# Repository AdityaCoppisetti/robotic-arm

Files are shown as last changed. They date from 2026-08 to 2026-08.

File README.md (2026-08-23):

# 6-Axis Robotic Arm

This project is a custom-built 6-axis robotic arm that I designed and built from the ground up. 
The arm has six degrees of freedom thus the 6DOF , I designed the mechanical parts myself and used a combination of 3D printing, custom gears ,and  almost each joint is a planetary mechanism since i really wanted to learn that and i learnt that in onshape .  The gripper usse MG996R V17 servo

The control side of the project is a custom pcb which is handled by a custom arduino uno nano that i made . the main pcb usees a4988 stepper motor drivers to drive each and every motor and the servo motor for the gripper i have connected directly . The plan is to use forward and inverse kinematics to move to a specific point instead of manually controlling every joint.

One of the things I want to experiment with later is turning the arm into a 3D printer by replacing the gripper with a printing head. This would make the robot more than just a robotic arm and i could then print alot of stuff from a arm that itself was 3d printed bahahahhahahaa

 There will probably be a lot of redesigns, and ill keep updating the journal.md of this repo for that 



i designed this robotic arm in onshape, 

joint 1 - 5 uses planetary gear mechanism where the sun gear is attached to the nema 17 motor



and then ive made the claw/ gripper 
which uses a servo motor attached to a spur gear which move yet 2 another spur gears



# how to assemble 

print the given step files , modify them if you want to 

and then look at the assembled version and piece everything together. i will be documenting my proccess aswell when i print the parts. 

# how to assemble electronic part of project

when you get the main pcb and then the microcontroller pcb
you take the stencil and then use that stencil to apply solder paste. 
and then you remove the stencil and place each component by looking at the nicely labelled pcb 



and then by using a hot air gun or a hotplate , reflow the solder 

# hot to assemble the main board pcb 

you take the pcb and using a soldering iron just solder the required amount of female or male pinheaders ( 2.57mm exactly) 

Screenshot From 2026-08-21 19-59-14

here is a mockup i nade using onshape of how the main pcb should look like after you assemlbe it

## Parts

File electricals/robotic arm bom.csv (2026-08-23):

No. | Component / Item | Price (inr) | Source / Purchase Link | Price (USD)
1 | Nano PCB | 900 | Robu.in | $9.40
2 | Main PCB | 1850 | Robu.in | $19.33
3 | Solder Wire | 229 | https://www.amazon.in/dp/B0GY9Q2VXC/ref=twister_B0GY9X7NQT?_encoding=UTF8 | $2.39
4 | PLA Filament | 699 | https://www.amazon.in/PLA-3D-Flexibility-Eco-Friendly-Compatible/dp/B071D82LDV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 | $7.30
5 | NEMA 17 Stepper Motor - 17HS4401S | 3204 | https://robocraze.com/products/17hs4401s-nema-17-stepper-motor?_pos=2&_psq=nema+17&_psid=cc221da5e&_ss=e | $33.48
6 | Zip Ties | 99 | https://www.amazon.in/gp/product/B08GKPWLB9/ref=ewc_pr_img_4?smid=AJ6SIZC8YQDZX&psc=1 | $1.03
7 | DC Power Jack Adapter - 2.1 × 5.5mm | 19 | https://robu.in/product/male-female-2-15-5mm-dc-power-jack-adapter-connector-plug-cctv-camera/ | $0.20
8 | 12V 1.5A Power Supply | 219 | https://www.amazon.in/gp/product/B0H1CTJV1Y/ref=ewc_pr_img_1?smid=A2DCS35WT32C19&psc=1 | $2.29
9 | A4988 Stepper Motor Driver + Heatsink | 432 | https://robocraze.com/products/original-a4988-stepper-motor-driver-module-with-heat-sink-for-3d-printer-red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 | $4.51
10 | 5-inch HDMI Touchscreen Display - 800×480 | 2359 | https://robu.in/product/5-inch-touch-screen-hdmi-interface-display-module-tft-lcd-800x480-raspberry-pi-2-model-b-touch-pen/ | $24.65
11 | Mechanical Switches | 399 | https://www.amazon.in/gp/product/B0FPR2ML31/ref=ox_sc_act_image_2?smid=A16FKXBMFHBYH0&psc=1 | $4.17
12 | Raspberry Pi Zero | 2000 | OLX.in bought it second hand , need reimbursement | $20.90
13 | 608 ZZ Bearing | 265 | https://www.amazon.in/608-Pieces-Double-Shields-Bearing/dp/B0H5T479XF/ref=sr_1_10?sr=8-10 | $2.77
14 | 1µF 0603 SMD ceramic capacitor | 55 | https://robu.in/product/mc0603b105k160ct-multicomp-pro-cap-smd-mlcc-1%c2%b5f-16-v-0603-pack-of-5/ | $0.57
15 | 100nF 0603 SMD ceramic capacitor | 11.6 | https://robu.in/product/cc0603jrx7r7bb104-yageo-16v-100nf-x7r-%c2%b15-0603-multilayer-ceramic-capacitors-mlcc-smd-smt-rohs/ | $0.12
16 | 4.7µF 16V SMD capacitor | 38 | https://robu.in/product/0805yc475kat2a-kyocera-avx-smd-multilayer-ceramic-capacitor-4-7-%c2%b5f-16-v-0805-2012-metric-%c2%b1-10-x7r/ | $0.40
17 | Yellow 0805 SMD LED | 7.55 | https://robu.in/product/0805-surface-mount-led-yellow/ | $0.08
18 | Green 0805 SMD LED | 14.44 | https://robu.in/product/0805-surface-mount-led-red-50-pcs/ | $0.15
19 | Red 0805 SMD LED | 7.2 | https://robu.in/product/0805-surface-mount-led-red-50-pcs/ | $0.08
20 | MicroSMP Schottky diode | 40 | https://robu.in/product/mss1p3l-m3-89a-vishay-intertech-30v-1a-440mv1a-microsmp-schottky-diodes-rohs/ | $0.42
21 | 0603 SMD fuse | 6.25 | https://robu.in/product/1uf-1000nf-50v-capacitor-0603-smd-package-pack-of-20/ | $0.07
22 | Mini USB-B female horizontal connector | 145 | https://robu.in/product/u-m-m5ss-w-2-hroparts-usb-2-0-1-5p-female-mini-b-smd-usb-connectors-rohs/ | $1.52
23 | 2.54mm pin header, 1×40 | 69 | https://robu.in/product/ds1021-1x40sf11-b-connfly-1x40-pin-2-54mm-pin-header-v-t-type/ | $0.72
24 | 1KΩ 0603 SMD resistor | 9 | https://robu.in/product/1k-ohm-1-4w-0603-surface-mount-chip-resistor-pack-of-100/ | $0.09
25 | SMD tactile switch, EVQPUK-style | 45 | https://robu.in/product/pts526sp20smtr2-lfs-ck-smd-tactile-switches-rohs/ | $0.47
26 | ATmega328P-M, QFN-32 5×5mm | 955 | https://robu.in/product/atmega328p-mur-microchip-8-bit-mcu-low-power-high-performance-avr-atmega-family-atmega328-series-microcontrollers-avr/ | $9.98
27 | LM1117MP-5.0, SOT-223 | 140 | https://robu.in/product/lm1117s-5-0-5v-1a-fixed-output-ldo-linear-voltage-regulator-3-pin-sot-223/ | $1.46
28 | FT232RL, SSOP-28 | 465 | https://robu.in/product/ft232rl-usb-to-ttl-5v-3-3v-download-cable-to-serial-adapter-module-for-arduino/ | $4.86
29 | 16MHz 3-pin SMD ceramic resonator | 50 | https://robu.in/product/1-month-warranty-802/ | $0.52
30 | raspberry Pi Zero cables and adaptor | 142 | https://robu.in/product/raspberry-pi-zero-3in1-micro-usb-cablepin-headerhdmi-adapter/ | $1.48
31 | velcro for claw/ gripper | 185 | https://amzn.in/d/0eumMNpg | $1.93
 |  |  | Total = $157.34 USD.

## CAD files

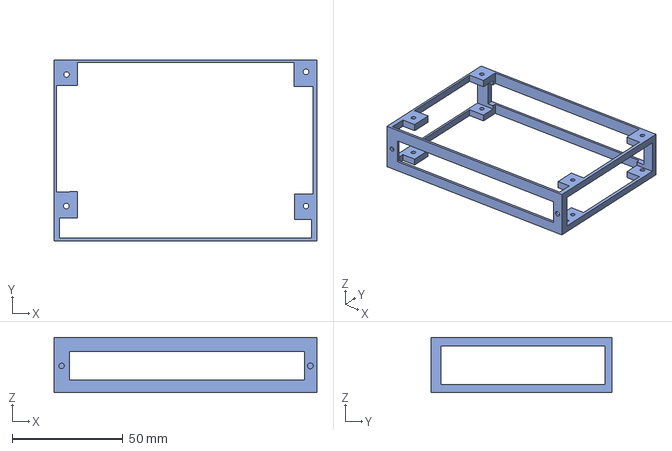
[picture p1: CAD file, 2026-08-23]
Robotic arm cad/main pcb case - Part 1.step
119.0 x 82.0 x 25.0 mm

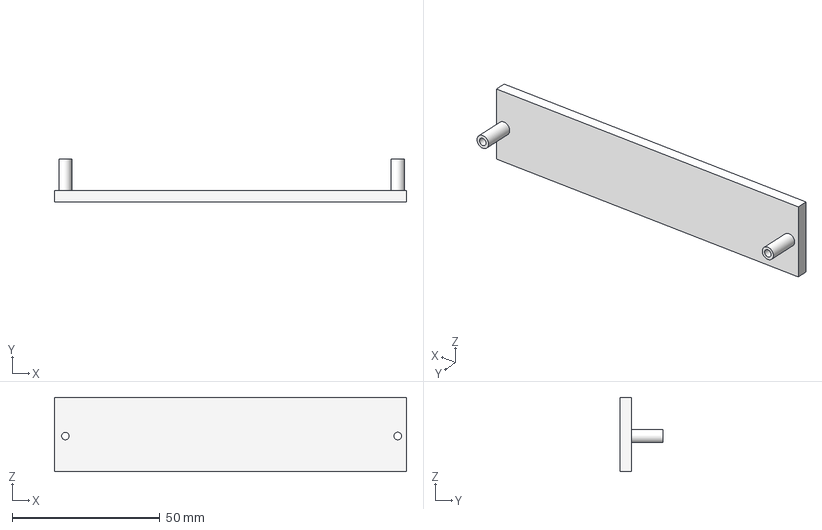
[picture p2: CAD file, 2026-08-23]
Robotic arm cad/main pcb case - Part 2.step
119.2 x 14.6 x 25.2 mm

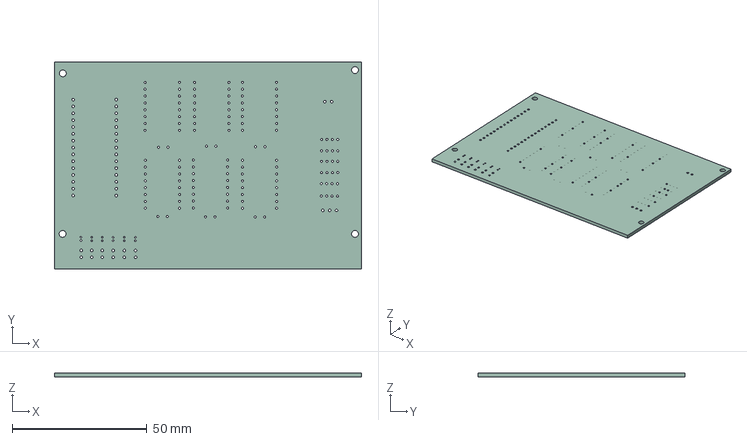
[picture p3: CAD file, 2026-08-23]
Robotic arm cad/main pcb.step
113.8 x 76.9 x 1.51 mm

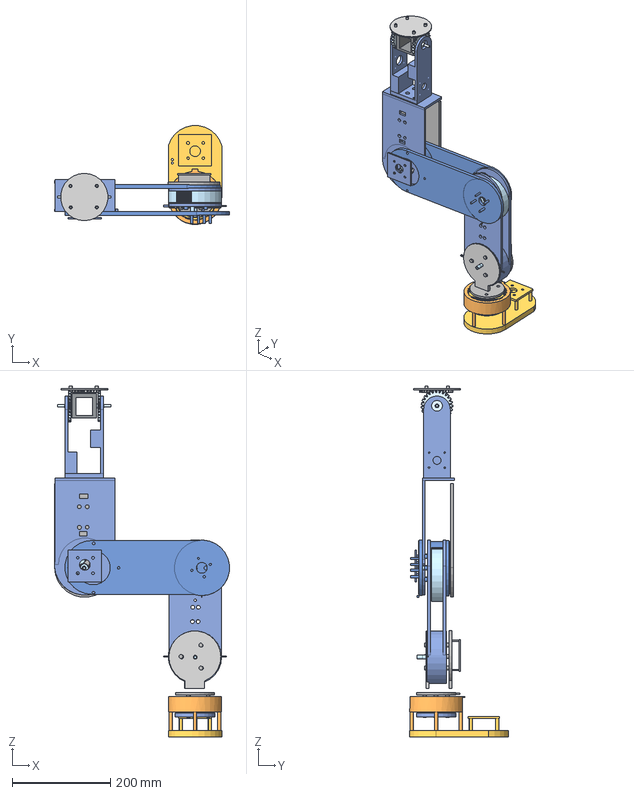
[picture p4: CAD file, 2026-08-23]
Robotic arm cad/assembled arm.step
357.1 x 201.3 x 716.0 mm
Spur gear (25 teeth) x 3

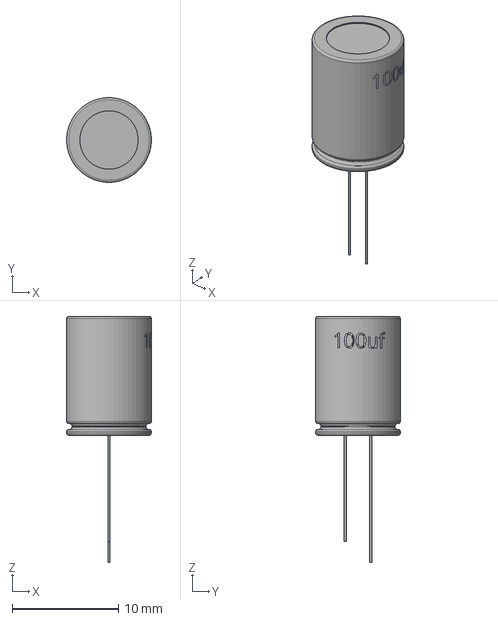
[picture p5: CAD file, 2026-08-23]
Robotic arm cad/100uf capacitor.step
8.00 x 8.00 x 23.2 mm

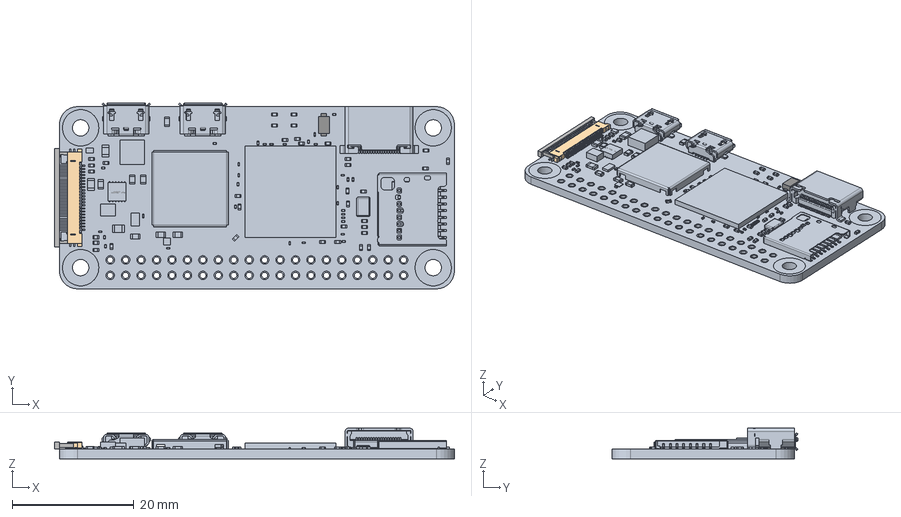
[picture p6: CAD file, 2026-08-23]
Robotic arm cad/Raspberry Pi Zero 2 W with Textures.step
65.8 x 30.6 x 5.05 mm

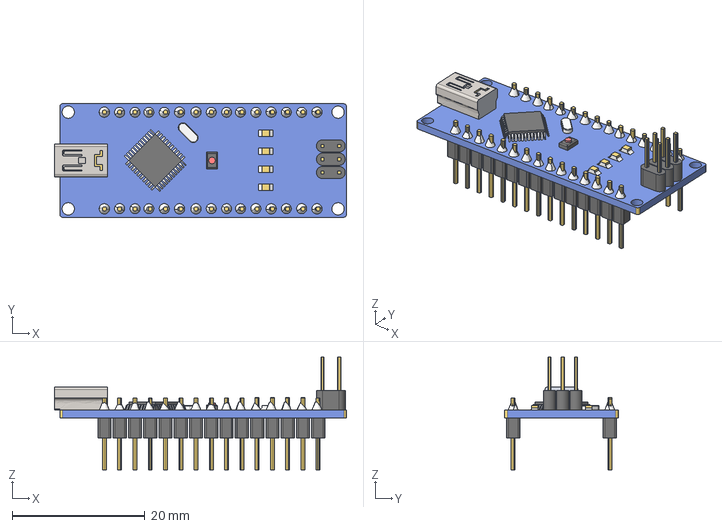
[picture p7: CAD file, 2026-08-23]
Robotic arm cad/Arduino Nano cadddddd.step
44.0 x 17.1 x 17.0 mm

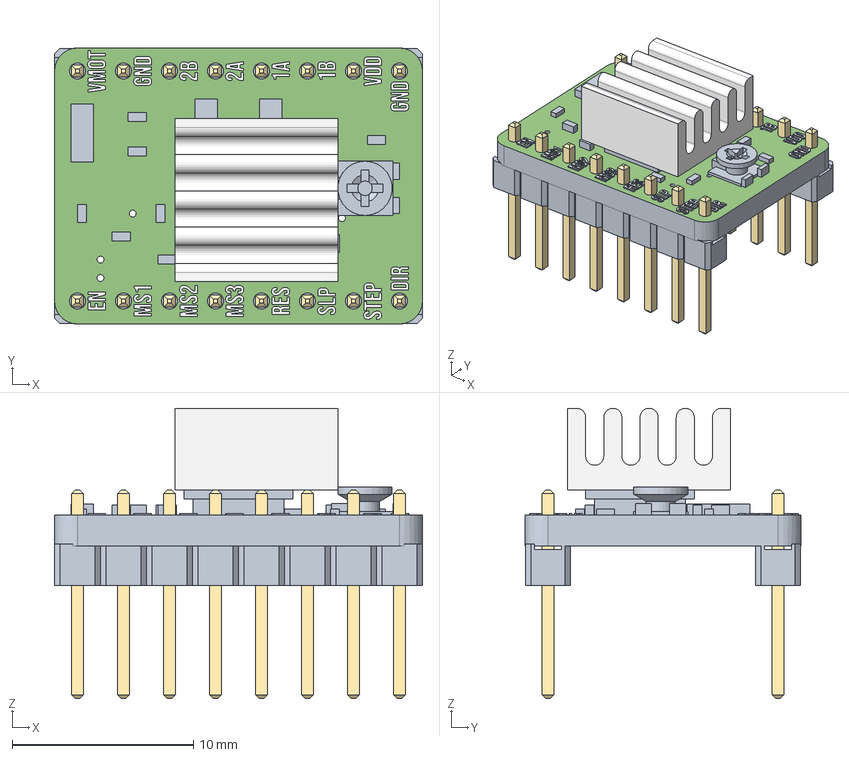
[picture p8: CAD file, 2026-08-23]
Robotic arm cad/a4988.step
20.3 x 15.2 x 16.0 mm

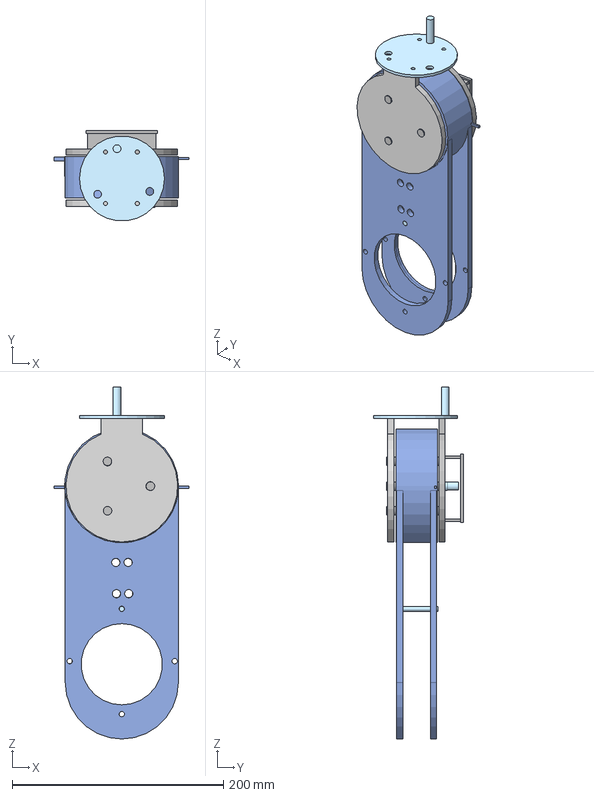
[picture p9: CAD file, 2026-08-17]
Robotic arm cad/joint 2 and link 2.step
127.9 x 85.7 x 333.5 mm

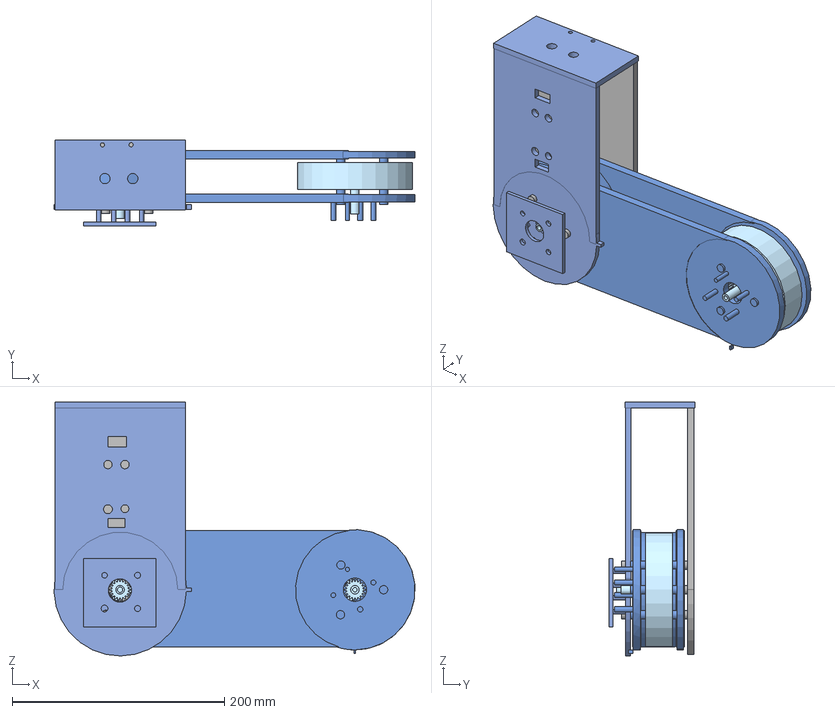
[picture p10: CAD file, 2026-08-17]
Robotic arm cad/joint 3 and joint 4 , link 3 and link 4 .step
339.9 x 80.5 x 239.0 mm

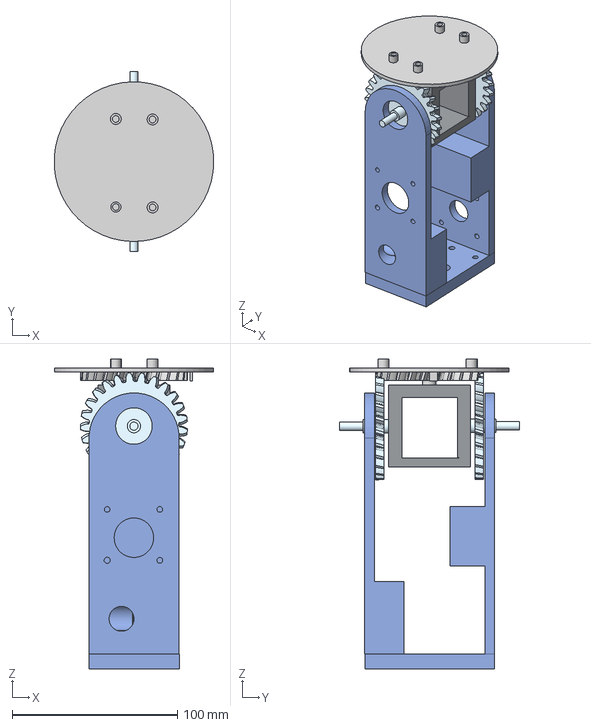
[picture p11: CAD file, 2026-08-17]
Robotic arm cad/2 DOF WRIST.step
96.4 x 109.0 x 187.4 mm

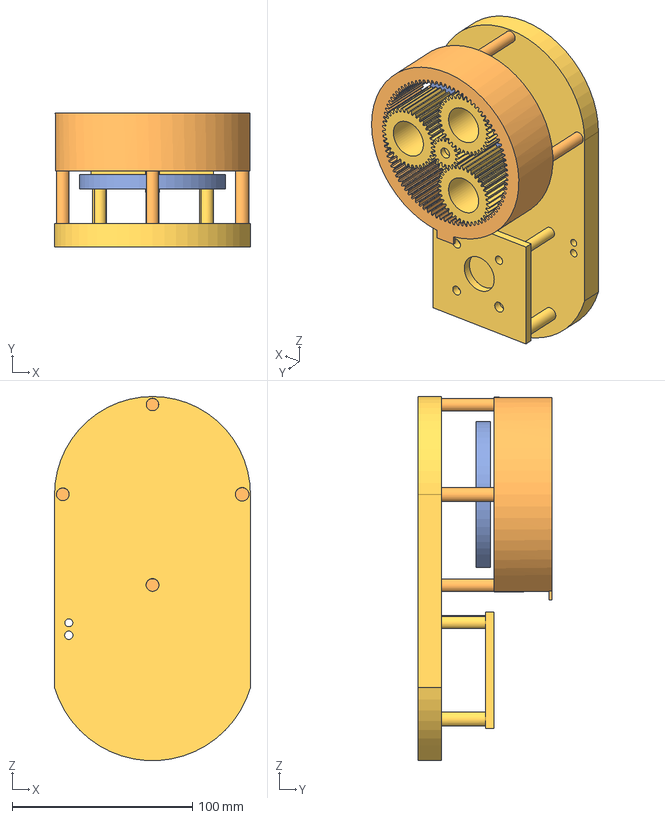
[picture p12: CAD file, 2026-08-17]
Robotic arm cad/base actuator.step
108.8 x 74.2 x 202.0 mm

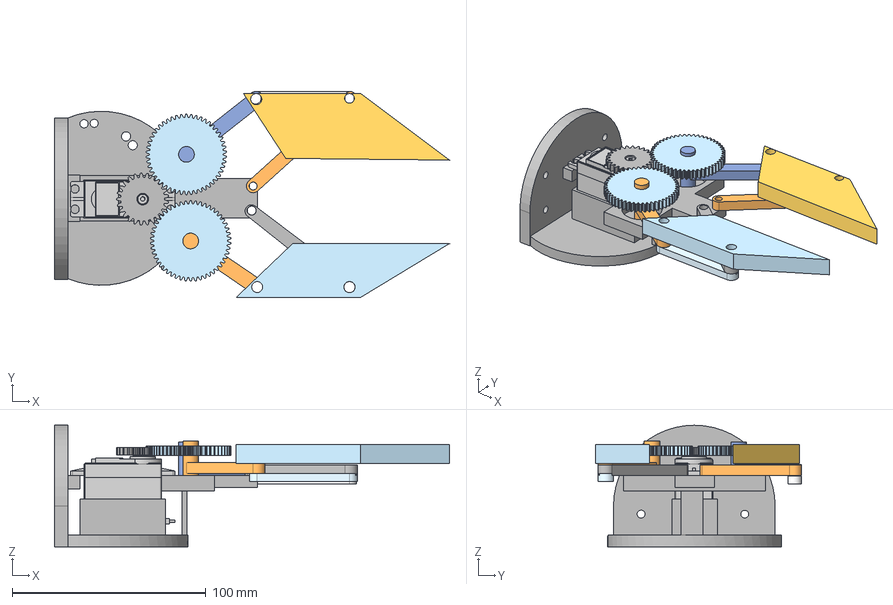
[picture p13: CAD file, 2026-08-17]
Robotic arm cad/claw-gripper.step
203.9 x 106.3 x 62.7 mm

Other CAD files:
Robotic arm cad/MG996R Servo Motor.x_t

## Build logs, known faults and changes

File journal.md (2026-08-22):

this is where ill be journaling my work.

Date- june-12/2026

time: 5:41 AM
today is 12th june but this is the work that i did on june 11th. due to a hectic and hot day i forgot to journal my work.

# THE ROBOTIC ARM BASE DESIGN

so i was searching for way to make this , thinking of a ton of designs and i thought this would be really easy. i was wrong.
i took me 45 mins until i landed on this- https://www.printables.com/model/930858-3d-printed-robotic-arm-actuator/files
this is whats called a planetary gear mechanism. very popularly used amoung projects like this.
Planetary gear mechanisms provide superior high torque density, allowing them to transmit large loads in a compact, lightweight design by distributing force across multiple planet gears



and i thought this would be incredibly easy to make but i was incredibly wrong.
until i picked up this project i didnt even know what a planetary gear shift system is. i have never worked on stuff like this and this is my first time using cad aswell.

i found this of great help! -https://www.thecatalystis.com/gears/
this is a website that helps you simulate the planetary gear system.
i was thinking of 3d printing the gears aswell but i found cheap planet gears on amazon- 
https://www.amazon.in/gp/product/B0G2J7PGLC/ref=ox_sc_act_image_1?smid=A3MLO3EZOE585&psc=1
the reason i went with this is of the material they are made of(nylon) and the fact they come pre prepared with bearings.

Screenshot From 2026-06-12 05-52-59

now now its okay if you want to save money and print the planet gears yourself, you can do that just double click on the mechanism and 
press center bore and then put the diameter bearing youre using

and so i opened the plantery mechanism similation on the website and typed in - 36 teeth in the planet ring.
and it gave me the other info that i needed.



and so i opened onshape and started a new document. 

you have to press the add custom feature button on the toolbar



and then you have to press this 



and then just search planetary gear.

you then have to go back to the planetary gear simulation and fill in the information accordingly.



MAKE SURE YOU PUT THAT YOU HAVE 3 PLANET RINGS.

( a few hours ago i had no clue what onshape even was and now im teaching in my github repo like wow what a nerd)

IF YOU EVER WANT TO LEARN MORE ABOUT GEARS AND THEIR MECHANISMS HERE IS THE BEST SITE IN MY OPINION-
https://www.3dmechanism.com/

now that the mechanism is done we have to work on whats called the **CARRIER**

now there are alerady a ton of good pre made designs in the onshape public library which i couldve used but once again this was my first time working with gears , cad and the whole circus.
so i desiced it was a good learning moment and i fucked around to find out.
here is the design i saw and i wanted to make this but i took me a WHILE to find out how this works.



this is the carrier design i had in mind. now this carrier is pretty well made but i wanted to know how it worked.
i couldnt use this carrier design exactly because its for 4 planets while we are only using 3. i think 3 is plenty
i couldve used just a simple triange as a carrier because of three planets but i lowk didnt know where or how to make a triangle like this-



but i did not understand it and that helped me in its own way.

i reverse engineered this- 



and made my own-
( i know it aint that good but its workable)



this is the base of the carrier because of the centre hole thats there so i can connect the sun gear ( the middle one) to the stepper motor.

and then this is the top one 


and then put together it looks something like this- 
all of this, including figuring out how to do cad and how onshape works and what planetary gear mechanism took me about 4 hours to figure out.

https://github.com/user-attachments/assets/15bbe72e-d050-4046-b9d4-a2d1aa677c6d

time logged- aprox 4.2hours

date- july 8th, 2026

yes i havent worked on this project in a while.
but i have made tons of progress

i made multiple joints. 
at first i was really really confused about what and how im gonna make the other joints. 
it may be because i havent done this kind of work in a while. it feels refreshing and really good to get my mind working again. 

ive made until this and only one portion remains. 

Screenshot From 2026-07-08 18-09-43

i know i know it looks weird but this is my first time making one and that includes first time using cad.

Screenshot From 2026-07-08 18-08-47

## okay so now onto the joint 2.



my idea was that if the planetary gears stay in place , the sun gear obviously stays in the middle, 
by that logic then the outer ring would rotate.

this is what i meant. 
i used the https://www.thecatalystis.com/gears/ website to demonstrate my idea.

https://github.com/user-attachments/assets/46c02f40-51b7-4518-86ec-1d51c42bed83

this is basically what i meant. 
notice how the outer ring is spinning and the planetary gears are spinning but not moving their positions.
also notice that the sun gear is moving in the opposite direction for it to move clockwise.

sun gear=anti clockwise
outer ring= clockwise.

keep this in mind cause its gonna be cruical to not forget.

in the "carrier" that puts the planetary gears in their position , i wanted to put small holes to put heat inserts into but onshape is glitching and not letting me do that so i might drill a little hole and put the heat insert that way



i put this motor mount but i lowk want to make it better which i will later on. instead of wasting filament to add structure i might just put like really long screws.



ALSO a really big mistake i made was that i was doing this to increase the length of my gears and allat. 

https://github.com/user-attachments/assets/ec140412-38f2-4429-8a6d-367094285359

which was basically just me copying the part and then stacking it on top of it and then combining it into one singular part using the boolean feature. 
it was extremely time taking oh god so i looked around and let me tell you that i felt like a dumbfounded idiot when i found that i can just do this

https://github.com/user-attachments/assets/3397579b-ed96-481c-a308-d51986f8bd29

you can just change the extrude depth here.



cause this at the same time makes the gear length also bigger.

this is my logic.



there is a tinyyyy tinyyyy gap there and i will be putting whats called a lazy susan bearing



this allows me to mount the pieces and let them carry that weight and not just hang from the carrier , but also the main support structure.

and then this is what the forearm looks like. it has holes to mount the outer ring to.



okay so earlier what we were doing was the outer ring was moving. 
but for this joint. the outer ring will be mounted to the forearm and the carriers will move. 
this is good for the weight distrubution.

this also gives me the excuse to use belt mechanism. i will be updating that dw. 

## now onto the joint 3.

i left a gap so that we could mont the outer ring carefully.



i put some holes in the ring because we need to mount it so we will put a thread insert.





these are to keep the gears in their disired spot



and then those "carrier are connected to another forearms and then connected to its own "outer ring" . 

all together it looks like this 



and then i made this. the forearm is short and then there is a flat sqare put on it. why? ill explain later. 

Screenshot From 2026-07-09 01-02-05

Screenshot From 2026-07-09 01-02-09

Screenshot From 2026-07-09 01-02-21

see the thing is for the wrist movement and attachment i want to make something like this- 

Screenshot From 2026-07-08 18-21-21

source- https://www.instructables.com/Yet-Another-3D-Printed-Robot-Arm/ 

you just have to scroll down a ton. dw its there. 

https://github.com/user-attachments/assets/bfe6638c-dc26-4a09-b7fa-06951944e07d

this is basically how it'll work. seems complicated but i know it isnt, pretty simple actually. 

https://github.com/user-attachments/assets/02b2b4d9-ed3f-49f6-b729-89860f96fb4b

I SAW THIS REEL WHERE THE MOTOR COVER , the filament part on the side was resin printed so it was CLEARRRRRRRRRRR WHICH WAS SO FUN!!!

I REALLY REALLY WANT TO DO THAT IF MY BUDGET HAS ANY ROOM. 

https://github.com/user-attachments/assets/cf3f4451-7ed7-4512-8826-a6093ded6a33

## august 2nd time - 10.54

# i just got done rebuilding the base of the robotic arms. 
there were several flaws -
1) the motor mount wasnt good and would leave the motor sitting by itself or like lifting the entire load.
2) i intend to use a belt driven planetary gear mechanism and that design wount let me do that so i had to redesigns everything
3) the base was too weak to carry the weight
4) there wasnt any space for limit switches
5) i increased the planetary gear depth and so needed to update the carrier since it was too short and wouldnt work

like look at how thin and bad it was previously- 



i think it had so many flaws because it was the first thing i had designed in cad after a LONGGGGG TIME 
so after a ton of practice building this project and many other i got faimliar with the software and cad itself and got slightly better at it.

here is what the new design looks like- 

Screenshot From 2026-08-02 10-53-35

here is a video showing the design properly -

https://github.com/user-attachments/assets/b235d558-9b16-4ba0-b130-88022c7480a6

the base i made with the intent to mount the motor to 



this will hold the motor aswell as give support to the base actuator. 

i put holes beneath to put heat inserts and then use screws and washers to secure it properly



mounted it would look smth like this- 



## sun gear

i changed the sun gear kinda , i added this middle support so i can put the gear and belt mechanism properly 



this basically- 



i went ahead and made a hole in the sun gear support cylinder so i can mount the belt gear mechanism easily.



once again these are the gear teeth and allat 



and then the carrier , i just have a cylinder running between each of the gears



and then at the very end of those gears i have added holes for heat inserts 



once again ill be using washers and screws to mount them securely. 
atp i should just use mansory glue lmao

and then for the limit switches i made this pretty simple mechanism 



althought i do feel like i should make it a bit bigger. 

all put together it looks like this- 

## 

## August 2nd 6.27 
i made some changes in the **joint 2**

i made a proper space for the motor and i put a lil tab for the limit switches



not much a difference 

OH AND i also changed the base plate of this part so i t mounts properly and accurately. 

## August 3rd 2.13 pm

i worked on all the joint's motor mounts and in the end i made this i have very minor changes to make and now i have to make the last 2 axis mechanisms. 



better view- 

https://github.com/user-attachments/assets/d6cfd987-f96c-4dd9-8066-cd05eacd0aab

## AUGUST 6TH TIME- 4.08PM

i actually made the 2 dof wrist yesterday and i thought that would be it.

heres how it looked , i deleted the file due to so many inaccuracies



there are so many faults i cant even 

https://github.com/user-attachments/assets/077f853c-312a-4f89-8bd1-733a6afe177f

as it turns out my calculations where wrong and bisdes that i had done alot of things freehand, 
and so i needed to redesign the entire thing again but with precise calculations.
i have to say i had alot of fun making this.

i followed some youtube video ( not tutorials just demonstrations) and made the design in my mind first and then carried it out in onshape.

i ended up with this oh and i used helical gears



i know it looks like i can make it more compact but i did measure everthing and the nem17 motors are 40mm ( 4cm ) and they wouldnt fit at all.



there is this cylindrical shape so i can put it on gearing and itll be able to rotate freely



and then this is so that i can mount Aluminum Timing Pulley. its 5mm.



and i guess i can call this square a carrier?



it has space for the gearing from the other side to go and the gears would stay in place.



and then this is the top surface where ill later put the gripper claw.



i also need to put a camera mounting thingy so that i can later on put a camera on it. honestly just my phone beause i dont think itll be able to handle the weight of my camera.

# now onto the whole holder which will house the nem17 motor 

this is the left side,


i plan on mounting the stepper motors on top of each other 

the motor width regardless of the shaft is 40mm (4cm) and so i put a little back piece there so the motors have no place to slide

and ill just put a piece of cardboard there or smth i dont know plus it gives a lil space for the wires.

also now do i think about it i need to put a lil limit switch bar on the surface mount

i added this little piece so that i can use it to press limit switches i mounted it on the surface plated because the surface plate is the one thats moving in two axis



also these are the measurements for the nem17 motors i found from the robu.in website 



and then here is the schematic design 



AAAAAAAAAAAAA I STILL NEED TO DESIGN THE ELECTRICALS AFTER IM DONE W THE CAD AAAAAAAAAA 

oh yeah back to the holder for the motor and allat

i included this lill space so i can put the wires thru this which looks good ig idk 
this would make the wiring easier fsfsfsfs



i then made this bottom mount so , im gonna put in heat inserts and then screw everything into place, and then i added to holes so that i can mount it using screws and washers onot the robotic arm itself

all put togehter this looks something like this - 



https://github.com/user-attachments/assets/72c732a2-6be2-4c8c-96ef-66e903738f73

also i realised allmost everyone else my calculations for the motor are wrong so im going to fix that, only minor fixes nothing to worry about alot

## AUGUST 7TH 

I worked on making the shoulder of the robotic arm proper, the closer i look at my designs the more i realise how much i fucked up.

i made it a bit better but i know in the future ill look back and sigh with all the inconsistancies. 

this is the improved version- 



i improved the carrier , i want to add bearing between the sun and planet gears and so i made a centre bore.



oh and the bearing i want to use are the 608zz bearing and its dimentions are- 
i used the extrude feature to make the hole in the centre but you can just enter the dimension here - 



i also change the base mounting plate it was really shit 

 

i made 4 tiny hole to put the threaded insert inside and then those 3 holes along with that weird cylinder are to mount it on the base planetary mechanism itself.
i was at first thinking of adding screws but just cylniders and some glue will help, you'll understand what i mean when i build it irl. 

and then i fixed the motor mount



believe it or not the hand drawn motor mount i made previously was not that far off in terms of dimension so i made it PROPER proper ykwim. 

all together it looks something like this - 

For the 608ZZ bearing:

Measurement	Millimeters	Centimeters
Inner hole diameter	8 mm	0.8 cm
Outer diameter	22 mm	2.2 cm
Thickness (width)	7 mm	0.7 cm

So in centimeters:

Inner hole: 0.8 cm
Outer diameter: 2.2 cm
Thickness: 0.7 cm

oh and i dont know if i mentioned this before- 



these holes are so i can put zip ties and cable put my wires neatly. 

here is how it looks all together 

https://github.com/user-attachments/assets/92ba4edb-455b-4546-ade4-a52e37fcf780

oh and i fixed the measurements in the base part of the arm- 



i fixed the motor mount and then i fixed the sun gear so that i can put a belt mechanism on it. 



and here is a lil 360 of the base- 

https://github.com/user-attachments/assets/05f1c04c-e099-472e-9303-c13885892532

okay so i made these lil holes so that i can put heat insert (this is the wrist mechanism) 



this is so that i can mount anything i want on it with ease. 

oh and i went ahead and fixed this- 



i think the arm is coming into great shape- 



whats remaining is to make the claw/ gripper

oh and i updated this aswell- 



## AUGUST 8TH 8.12AM 
GOOOOOOOOOOOOOOOOOOOOOOOOOD MORNINGGGGGGGGGGGGGGGG 

yesterday i made the claw/gripper mechanism and i had alot of fun making it!
i had this design in my mind ever since i started



here is a tutorial kinda? its just saying how it works 
https://www.instructables.com/My-Big-Robot-Claw/

and basically how it works is- 

https://github.com/user-attachments/assets/29d53f73-7ce6-4bcc-ba2c-e7f5372ba941

 and so i started making the design in onshape and at first i made this disgusting design and thought it would be okay 

 Screenshot From 2026-08-07 17-57-44

yes i know it looks so bad. i lowkey thought i would leave it be but then i got this urge to make it better and i thought why not give it another try and i made this which is much better in my opinion



now this is much much better than the earlier design.



im using 3 spur gears , 2 of them connected to the claw mechanism itself and then one is connected to the servo motor.

in this design im using the TowerPro MG996R Digital High Torque Servo Motor.

this is better than the shitty low quality servo motor 

and i wanted to design my cad design as precise so i pulled out this specification of the motor

AWN9abVES4HJeKg18x0a8sXqbF1AeTm1wUe4BqLj

but then i did not want to redesign the entire motor in onshape so i looked in public documents if someone had already deisgned it for me and sure enough someone had deisgned it!



i did measure it to see if it was accurate and it is 

ill add the servo motor copy file into the repo!

all of this is making me wonder if i should redesign the forearms now cause they look really bad 

and so i followed that design on istructables.com and i made my design

here is how it looks like from beneath.

and then i made the the mount/ motor mount. i made it so i can mount it to the 2 dof wrsit. 

i added this with holes so i can put heat inserts and mount it properly 



okay so this is how the mount for the motor looks like- 



i have even added a hole for the wires to go thru and added holes to make sure the motor stays in place!

i went ahead and added this support structure so the motor does infact stay in place 



oh and these holes are there so i can put it with bearings 

and i added these holes for cable management using zip ties

## august 13th 

i will be redesigning the forearms because they are hideous and not properly measured 

lets do the forward and reverse kinematic of the arm tomorrow since its pretty late , lets for now design the robotic arm electronics hardware

my idea for the robotic arm is that i control it with the raspberry pi zero 2watt that sends the microcontroller directions on where to move and then 
with the help of the stepper motor controller , the motors move. 

so lets define that properly 
and why im using a raspberry pico in the first place

i want to use my robotic arm to 3d print stuff with the help of a hotend attachement , so i just want the raspberry pi 2w to take in the stl or .step file and then convert it 
into directions the microcontroller will be able to read and then tell the arm where to move and how to move 

## AUGUST 16TH

i need to finish up with cad man seriously this has taken so long 
okay so i will be removing the limit switch bits that i made. 
because all i want is -
it to calibrate and then find the origin and then i can virtually set the mechanical stops 

these are my tasks for today after im done with cad 

1. **Define the 6 joints** — identify J1–J6, what links they connect, their rotation axes, and their movement limits. 
2. **Build the kinematic model** — define the coordinate frames and transformations between the joints. 
3. **Export my CAD links as meshes** — usually STL/DAE for ROS. 
4. **Create a ROS 2 package** for your robot. 
5. **Create the URDF/Xacro** — links, joints, axes, positions, limits, meshes, and inertial properties. 

oh and then i also want to design the physical electronics hardware with the microcontroller and the stepper motor drivers , see here is what i have in my mind , 
i want the micro controller to control the stepper motor and tell it where to move with g code basically like x= 120 , y= 120 , z= 0 , basically coordinates and the stepper motors will move accordingly.

see my plans with this robotic arm is to make it 3d print stuff. 
i want to add a raspberry pi running ros2 and MoveIt 2. when we upload our file into our 3d printer it creates it into g code which our robotic arm can read and thus it will give the microcontroller where to move and then the microcontroller will tell the stepper motor drives the required data. 
im adding a raspberry pi because i can run ros2 and moveIt 2 on it and it has the capabilites to extract the g code plus ill be able to add a screen and knobs for more functionality.

if i have the time to add all of this i will otherwise the raspberry pi along with the extruding part will be part 2 of this project and probably in a different github repo 

lets do all of this in a day , today is august 16th lets set this as todays task

i have finished with the base cad design which we will be defining as the J1 ( joint one) 

i added holes in the planet gears so i can put a gearing in them because i want everything to be really smooth

on the outer ring , there is this little rectangle bit , thats where the limit switch will go , why?
so see my plan is that when the robotic arm turns on , its going to need to know where the origin is , so its going to perform a calibration routine where the ring will rotate until it hits the limit switch and thus itll define the origin point

now lets define the J1

## JOINT 1 (J1) 

joint-1 is the base of our 6DOF robotic arm 



# so lets define it!

1) parameter - J1
2) joint type - revolute
3) parent - base_link
4) child - link_1
5) output- grey planetary carrier( meaning that the final output of everything moving in this joint will be the carrier that moves)
6) rotation axis - vertical z
   
since this is a planetary gear mechanism we will have to define sun teeth and planetary teeth and all that aswell

7) sun teeth - 18
8) planet teeth - 36
9) ring teeth - 90
 10) number of plants - 3
 11) ring- fixed on spot
 12) motor- nema17
 13) motor- pulley 20T ( 20 teeth)
 14) sun - pulley 20T
 15) belt reduction - 3:1 ratio
 16) planetary reduction - 6:1
 17) total reduction - 18:1
 18) joint range -180 degrees to +180 degrees
 19) calibration - will be this little program ill write that would perform before anything starts where it'll mechanically define the origin
 20) j1 angle - motor angle ÷ 18
 21) motor rotation for +180 degrees j1 - 3240 degree / 9 revolutions
 22) full motor rotation for J1 range - 6480 degrees/ 18 revolutions 

so i guess thats it there defined but i may be missing something i dont know we'll see later , lets get onto joint 2 (j2) 

## JOINT 2



this is the joint 2 (J2) which will sit on top of the base this is also our forearm ig 

unlike the gear mechanism, the sun gear is directly connected to the stepper motor , and not using the synchronised belt mechanism 

this is the planetary gear mechanism  info 



# Details 

1) joint type - revolute
2) parent - link_1
3) child  - link_2
4) mechanism - planetary gearbox
5) motor - NEMA 17
6) motor connection - directly to the sun gear
7) sun teeth - 18
8) planet teeth - 36
9) ring teeth - 90 teeth
10) number of planets - 3
11) ring is fixed the carrier moves
12) reduction 6:1
13) rotation axis horizontal
14) joint range is 180 i keep forgetting this always
15) calibration is routine to find origin point using limit switch

 do you wanna know something funny? 
when i was figuring out the joint range in onshape i counted the joints and only counted 5 cause there are only 5 technically because we are using the 2dof robotic wrist so i got so baffled onto how i missed an entire fucking joint BAHAHAHAHHAHAHAHA

apparenly i had made a mistake when putting the limit mechanism part of the joint 3 because it wasnt in line with the planetary mechanism's ring and which would have resulted in a differented origin and thus a different 180 degree point than anticipated 

here it is  fixed 



## JOINT 3 



this is the joint 3 which is connected to the link_2 and moves the link_3 
and even in this mechanism , the sun gear is attached to the motor directly and not using a synchronised mechanism 

here is the planetary mechanism info 



# Details 

1) joint type - revolute
2) mechanis - planetary gearbox
3) motor - NEMA 17
4) Motor is connected to the sun directly
5) sun teeth - 18
6) planet teeth - 36
7) ring teeth - 90
8) number of planets - 3
9) ring- fixed
10) output is carrier because only the carrier will be moving
11) reduction 6:1
12) joint range 0 degrees to 180 degrees
13) calibration - origin is 0 degrees
14) motor is at joint - j3+ motor angle ÷ 6
15) motor rotation for 180 degrees J3 - 1080 degrees / 3 revolutions
16) 

## JOINT 4



this is the joint thats attached to the link_3 and it moves the link_4 which supports the 2dof wrist 
to figure this out we will need to perform transmission matrix 

because the 2dof wrist uses intermeshing 

this is the planetary gearbox info 
 


also in this the carrier is the output

# Details
1) joint type - revolute 
2) mechanism - planetary gearbox
3) motor - NEMA 17
4) motor is connected to the sun gear directly
5) sun teeth - 18 teeth
6) planet - 36 teeth
7) ring - 90 teeth
8) planets - 3
9) ring - fixed in place
10) output - carrier
11) reduction - 6:1
12) range 0 to 180 degrees
13) origin is 0 degrees
14) motor to joint angle - J4 = motor angle ÷ 6
15) motor rotation for 180 degrees - 1080 degrees/ 3 revolutions

    now for our J5 and J6 we are using a 2 dof wrist

     so its going to be much different 
we also need to remember while calculating that we are using 2 synchronised belt mechanisms for this



the key thing is that J5 and J6 and still two independent joints so we will have to figure out the transmission from each motor to its respective wrist axis 

# for each motor belt system we will have to count ( btw both belt systems are the same ) 
1) motor pulley tooth count - 20
2) driven pulley tooth count - 60
3) there is only one belt stage 
4) the belt is open 
5) lets say motor 1 drives J5 and then motor 1 and 2 both drive J6 together , 
6) direction of rotation is anticlock wise and clockwise 
7) mechanical range is infinity 
8) motor to join ratio is 3:1 
9) 1 motor revolution - 120 joint rotation 
10) 3 motor revolutions - 360 joint rotation 
11) joint angle = motor angle divided by 3 

i am using helical gears for the 2dof wrist.

each helical gear is the same , there are 3 gears , gear 1 is controlled by motor 1 and then gear 2 is controlled by motor 2 and gear 2 and 1 mesh with gear 3 . 
motor 1 rotates to spin gear 1 which revolues the gear 3 in z axis and then motor 1 and 2 both move together to move the gear 3 in horizontal axis 

OKAY SO WAIT I MESSED UP THE EXPLAINATION 

you know how i said that motor 1 rotates the gear 1 which meshes with the gear 3 and rotates it? 
well in order for the gear 3 to spin , the motor 2 that rotates the gear 2 has to rotate in the opposite direction 

i.e to move the gear 3 in z axis like the base mechanism axis , the motor 1 rotates anticlockwise and the motor 2 rotates clockwise 

okay ive done the calculations now lets define the joint 5 

## JOINT 5 



# Details 

1) joint type - revolute 
2) parent - link_4
3) child_ link5 
4) mechanism - 2-DOF differential wrist
5) motor inputs - M1 + M2
6) M1 transmission - 20 teeth to 60 teeth synchronised belt mechanism 
7) M2 transmission 20 teeth to 60 teeth synchronised belt mechanism 
8) belt stages - 1 per motor 
9) belt type - open 
10) belt reduction 3: 1 
11) helical gear - gear 1 , 2 and 3
12) gear teeth - 25 teeth each 
13) helical gear ratio 1:1 
14) J5 motion - rotation about z axis 
15) motor movement for j5 - m1 ccw + m2 cw 
16) reverse J5 - M1 CW + M2 CCw
17) mechanical range - contrinuous / unlimited 
18) calibration - origin is 0 at limit switch
19) mechanical / software range - 0 to 180 degrees 
20) reverse direction - opposite motor differential 

my startup sequence is - 
power on - motor controller started and then homing routine and then enable normal motion and ros 2 and moveit 2 starts commanding joints

## JOINT 6 



this is the same as joint 5 just opposite

# Details 

1) parameter - j6
2) joint type - revolute
3) parent - link_5
4) child - link_6 ( basically the end effector)
5) mechanism - 2 Dof differential wrist
6) motors - m1+ m2
7) m1 belt - 20teeth to 60 teeth pulley
8) m2 belt - same as above
9) belt stages 1 per motor
10) belt type - open
11) belt reduction 3:1 each
12) helical gear - gear 1 , gear 2 and gear 3
13) helical gear teeth - 25t each
14) helical gear ratio - 1:1
15) motion - rotation about the horizontal wrist axis
16) motor movement - m1+m2 move together
17) origin - established using custom homing routine
18) range - 0 to 180 degree
19) ros joint limit 0 to pi radians

see my wrist has two independent DOFs generated by 2 motors 
for j6 the motors move together to produce horizontal axis wrist movement 

so we do not treat j6 as simply - 
j6+ m2/3 
because m1 and m2 both participatein the differential 

with that now , 

we have defined our all 6 joints and now we have to define the links 

let us now look at cad and define the links. 

## LINK - 1 

okay so we are going to take link_1 as the part thats rigidly attached to the J1's carrier 

we dont really need mass , centre of mass , intertia right now as that can be extracted from cad later on so lets define the link_1 (link1)

# DETAILS 

1) rigidly attached to J1's carrier
2) parent joint - base_ link
3) motion - rotates with J1
4) J1 to J2 axis distant is 66.91 mm
5) j1 axis - vertical z
6) j2 axis - perpendicular to J1
7) j2 assembly base - rigidly attached to J1 carrier

# what belongs to link_1?
everything that moves together when j1 moves including the rigid structure connecting the j1 carrier to the J2 
assembly

we have everytihng needed for kinematic definition for link_1 lets get onto link_2 

## LINK- 2 ( Link_2) 


link_2 is the assembly attached to the J2 carrier / output that rotates around the J2 axis and carrier J3

# DETAILS 

1) parent - link_1
2) parent joint - j2
3) rigidly attached to j2 carrier output
4) contains - j3 gearbox and its fixed components
5) j3 fixed ring - part of link2
6) j3 rotating carrier - not part of link 2 because it becomes link 3
7) j2 to j3 axis distance - 16.583cm

8) movement - rotates with j2
9) j3 mechanism attached to the link 2
10) j3 fixed components - part of link 2
11) 
    
## LINK-3 ( link_3) 



# DETAILS

1) Parent link - link_2
2) parent joint - J3
3) rigidly conncted to - j3 carrier ( the output
4) connected - J4
5) role - rigid forearm section between j3 and j4
6) movement - moves with J3
7) j3 to j4 axis distance - 22.110cm

   the J4's gearbox is fixed to link 3 belongs to link 3 , the rotating output of J4 becomes art of link 4 

## LINK-4 ( link_4) 


# DETAILS 

1) parent link - link_3
2) parent joint - J4
3) rigidly attahed to J4 carrier / output
4) J4 wrist ( gear 3 axis) - 36.403cm
5) j4- wrist axis - 364.03mm
6) movement rotates with j4
7) endpoint - 2dof wrist

# THE CLAW / GRIPPER ( end_effector) 



i want grip in the claws so ill be adding the rough part of velcro on the grippers. like those adhesive velcro you can find on amazon 

however we arent yet done to move onto kinetic module because we are using a servo motor to open and close the gripper. lets call is gripper actuator 



the servo motor will start from origin point and since its a servo motor i wont have to use a calibration method 
involving a limit switch 
and in the image above look that is how the servo motor works , it spins a spur gear which spins 2 more spur gears that are attached to claw 1 and claw 2 and they move and close. 

now lets define the gripper 

# **DEFINING THE GRIPPER**

complete structural definition - 

1) type - end effector
2) attached to - 2 dof wrist output
3) wrist to gripper reference - 156.844 mm
4) arm dof count - 6DOF
5) actuator - mg996R v17
6) servo calibration - not required
7) control - open / close
8) servo gear - 25 teeth
9) claw 1 gear - 50 teeth
10) claw 2 gear - 50 teeth
11) gear stages - 1
12) transmission- 2:1 reduction
13) servo to claw gear - 2 servo rotations - 1 claw gear rotation
14) claw gear angel - servo angle / 2
15) claw 1 & 2 - driven symmetricaly by th servo gear

this is the info for the large spur gears 



and this is the info for the small spur gear attached to the servo motor 



THE DEFINITION OF ALL THE JOINTS AND LINKS ARE NOW DONE AND WE ARE FINALLY READY TO MOVE ONTO KINEmATICS 

however i think i should now design the electronics part of this project. 
basically ill be making a custom pcb with a microcontroller and the pin headers for the stepper motor driver and then the input pins for the stepper motor itself 
and ill add a space for the raspberry pi zero 2w aswell since ill be using that to give g code to the microcontroller.

 before i get started on the hardware , since we are done with the cad , lets add the cad files into the repo 

my plan is that i want a microcontroller to control all the stepper motors and i want a raspberry pi to give it g code to print files or stuff because later on , ill be able to add a camera to my 
robotic arm and then be able to tell it to see things and pick them up. 
i believe that there is already an LLM model for that 

# stepper motor driver 

ill be using 
# **a4988 stepper motor driver**



to control my nem17 stepper motors , since they only take like 1-2 pins from the microcontroller and they are well documented 

what people usually do when they use these many a4988 stepper motor drivers is that they buy this hideous shield for their arduino uno 



which i mean technically does work but its looks so terrible

the pricing on these is just fucking weird 

on amazon for just 4 of these here is the price 



and then here is the price on robocraze - 



 for a total of 6 drivers it would cost me - just 432 ruppees , which is really fucking cheap 

 plus i really like the green look , it would look really good with a black pcb 

 please excuse my shitty drawing , here is how i want my pcb to look like 

 

 apparently the whiteboard website lets you use shapes so this was easy to make. 

 i want there to be external power port that will provide the power to the stepper motor and then i think the board will take power from the microcontroller itself? 

 oh and in this explaination design above i havent added space for capacitors and the output for the servo motor 

 as much as i do want to use a pre-made micro-controller but that wouldnt really help my kicad skills and right now i need to build as much as i can 

 ill be using wokwi to show how to wire a driver with the microcontroller

we start off by joining the sleep and reset pins together so that the board isnt in sleep mode 

 

 the reference design is this from a youtube video 

 

this is my design on wokwi



let me just explain from what ive understood , 

you power the driver from the microcontroller and the driver supplies power to the stepper motor along with the data , so you connect a external dc power supply jack and wire it to the driver using 
jumper wires but you add a decoupling capacitor of 100 microfarad so that there arent any ripples in the voltage. 

aaaaaaaaaaaaaaaaaaaaa ill have to build my own microcontroller which is fun but ughhhh its going to take so much time and also i wont be adding wifi to this because i will already have wifi capabilities because ill be using the ras pi 

i usually use the esp 32 to build my microcontroller but this time im going with arduino since i need a change of components and design kinda 

luckily we do have the driver footprint in kicad 



ill be building the arduino nano to use as my microcontroller

lets make the schematic 

## ARDUINO NANO SCHEMATIC 

the schematic consists of 4 parts well 5 parts if you include the mounting holes

i will be using the arduino nano because it compact and really easy to make , you can use an external one , however i want to enhance my skills and i love building custom microcontrollers so i 
decided to build my own 

# the ATmega328P-M microcontroller chip 



i like to keep my texts small so if you want to recreate this , it'll be in this github repo 

# the usb- b and FT232RL usb interface 



i think i will be going over this again and including a type c port but then since im a photographer i have a ton of cameras which use that pin so i already have a ton of wires laying around which arent
being used 

# the general purpose input output pins (gpio pins) 



well these are just normal pinheaders so idk what to say tbh 

# LM1117MP-5.0power management 
this is what manages the power in the board ig 

i actually dont know if the raspberry zero 2w will be able to supply the needed current for the microcontroller
okay so ssince im using a classic arduino nano ATmega328P , i can use the usb to power AND communicate to the arduino nano over usb. 

apparently there is something known as esp nano woah when did this even come out , i think im going to either build or use this board for my next project 



# mounting holes 



mountain holes lalallala

lets build the pcb now 

## THE MICROCONTROLLER PCB 

Here are the components after we update it from the schematic 



but before you do this you need the required footprints and here they are- 





now lets get onto making the pcb 

okay so the way i was routing everything was a big mess so ive deleted the first design and it wasnt much that i wouldve shown so im just going to start designing it again 

here is the physical board stackup 



here is how the board looks like so far i am still placing components 



Also i removed the mounting holes and the testpoints as i want this to be as compact as it can be 

im also i placing alot of components on the other side of the board as its a tiny and compact board

this is shaping out to be so good and its making me realise how much more i have to practice



it looks so so good 



i finished placing my components ive gotten so much better at ts 



i fucking love building custom pcb's its so funnnnn



ALLLLLLLLLL DONE WITH THE ARDUINO NANO ROUTING IT LOOKS SOOOO COOOOOL 

i actually forgot to add fill zones

and then i want to add a usb c im not actually sure about that , and then i need to build the entire pcb and not just this

also at first i made the edgecuts layer very very weird , but im okay with keeping it as a rectangle

im perfectly okay with this 



i added fill zones 



i added one fill zone for each layer 

here is how the pcb looks like in 3d view

here is the top of the pcb 



here is the bottom of the pcb 



and i'll obviously give a lil 360

https://github.com/user-attachments/assets/e9517a0c-779f-49d6-9484-9a5c57885ef6

okay so the microcontroller is done and i still need to make the main pcb and i also have this mount in mind so that i can attach the pcb on the base of the robotic arm 

now see i have 2 options for the main pcb 

option 1 - have the arduino nano be on the main board permanently 

option 2 - have the arduino nano be connected to the main pcb using pinheaders 

now i actually prefer the option 2 

why? 

i would then be able to use the arduino nano externally and however i want , rather it being used just for the robotic arm 

i have a keyboard project which has an led matrix module which i could use with the arduino nani and make it into a badge 

okay so now here is what im going to do , i going to create a new project called " main pcb" and im going to rename this project as arduino nano 

starting with a blank sketch

here is what im going to do 
im going to copy paste the pinheaders from the arduino nano and then wire everything on the main pcb using that.

i was just a little confused with the capacitor in each circuit so i checked it out on youtube , it wasnt much help but i found this 



but see i wont be putting a 12v external plug for each stepper motor because thats 6 plugs and it wouldnt make sense

so i will adding just one one external power supply port and i guess i already have one because my friend bought it for his raspberry pi , but i dont know it thats safe . 

This is how ive wired the module 



and you must be wondering that there are 2 types of ground and that is because the module 

is taking power from the arduino and then it is also taking power from an external 12v power supply to give to the stepper motors 

which means that we would also have to change that in the pinheaders we copied from the arduino nano schematic and label them as gnd_1

this is how that looks like 



I have labelled everything in the manner that it indicates that its module 1 out of 6

you can take a look and just figure it out 



ive added the number 1 in front of the labels 

and ive named the J1 ( the pinheader for the motor to plug into) as BASE so that its easy to identify

for the rest ill be naming them joint wise 

i.e ill be naming them joint 1 , joint 2 and so on 

i also forget that we need to add a capacitor to the circuit along with a diode

i added it in the schematic 



its a 100 microfarad capacitor

also i need to add output for the servo motor in the gripper

this is the module 1 

if you prefer you can add the smd capacitors 



but i want through the hole ones as i like soldering them for some reason and they are pretty cheap 

 the important rule is that the capacitors voltage rating must be higher that the voltage im applying 
 so the supply is 12v 
 and the capacitor is 100 uf , 35v so thats perfectly safe to use 

i will be using this capacitor 



 also i removed the diode as its smoother without it 

the second module is the same just the labels are different

here is how that looks like 



now lets get working on the 3rd module , we will basically repeat this till we have the required 6 drivers setup

Completed the 3rd driver , i lowkey sometime make one of these modules on my own 



3 more to go! 

4th one done 



2 more to go!

5th one also done 1 more to go 

and then servo motor 

Im done with all 6 

here is how they look 



oops forgot to connect it to the nano pinout

here is how that looks like 



notice how i changed the pinout for gnd to gnd 1 

now lets wire the servo motor 

## final schematic 

here is how the final schematic looks like 



okay so i now have to build the pcb and then i have to design a stand or like smth for it because i dont want just the plain pcb on the desk 

i also added a dc jack in the schematic 

i dont think i have wired it correctly but its okay since ill be buying a external dc jack input



# footprints for the main pcb 



#               MAIN BOARD PCB 

These are the components in the pcb editor for the main pcb 



now lets place them and make the pcb!

im finally done with the routing 



Here is the finished pcb with all the routing and even space for the raspberry pi , 
although i do not like the space on the side so i might build something there ( keyboard led matrix foreshadow , wait 
i could add glossy keycaps to turn it on or off!!!! this is so fun) 



here is how the pcb looks like in 3d view



and the bottom 



and obviously here is a lil 360 

https://github.com/user-attachments/assets/e47a3eab-e3a3-4c1f-93bd-4d83aabd0c61

# AUGUST 21ST 

i removed the raspberry section from the pcb , not because im removing the raspberry pi but because i think it looks weird with that free space beside it , 



its either i remove it entirely or i put something on the free space 

althogh you know what i do have this idea 

i want to put keyboard switches as functional switch on the side of the pcb in the free space

i would add 4 switches 

1 would be connected to the en on the drivers so that i could stop them in a emergency. 
and then one would be for the calibration , i want to do the auto calibration in the software however i do want the option to have a manual button , plus glossy keycaps would go so hard . 

and then the 2 buttons could be used to go up and down on the menu and then long press on a button could be used for selecting something 

also i dont want to have to externally power the raspberry 2w as i dont want the hassle of using all the plugs i have , i could howver fix this problem with a extension chord, i would like to make it so its not a mess of wires 

also on top of the raspberry pi i want to add a screen that will show the robot in ros or moveit ykwim plus i would be able to access it remotely 

if i mount the raspberry pi on the back of the main pcb along with the capacitors then make a 3d printed bracket adaptor for the screen that would make it so much less bulky. 

but in order for me to do that i need to find a display that isnt a raspberry pi HAT so i can use normal cables for it and not like a whole fucking mess , plus i want one that doesnt have many cables going into it 

i also want to add a mid sized character lcd display because i think thats super cool 
i found this hdmi display but i guess that would just add a long hdmi wire to everything plus its like 5 inches big i dont need a display that big 

okay so i wont be adding that dc jack after all 

ive decided that im going to keep the main pcb like that because i dont want everything on one board 

also i will be putting a dc jack on the main pcb that will output the 12v so that i can power the pi zero 2w



giving  the raspberry pi zero 12volts will destroy the board so ill just give it external 5v from a charger that i have 

because it also needs to supply power the the custom arduino nano microcontroller that i made which reminds me i need to put custom images on the board

with all that i guess im done with the main pcb but just one small thing is remaining , i want to create a custom 3d printed stand thingy for it and ill be making the front end with the raspberry pi and the display along with the glossy keycaps , the screen will be showing the raspberry pi running ros alongside 

another thing to change is that i incorrectly labelled the joint pinheaders on the main pcb 



the labeling here indicates that there are only 5 joints as ive labelled one as base and then said joint 1 and onwards so i need to fix that 

Now that its done lets make holes so that i can mount the pcb on the 3d printed mount ill make 

i made the holes and here is how they looks like 



now lets make the pcb mount on onshape 

and to get everything precise i will be exporting everything in .step file 



before that here is the compact version of the pcb with the fill zones 



now that we have have exported that as step , we also have to export the arduino nano that we made in .step file

and now we will open onshape and import our boards



when exporting we want to keep them in the same part studio



here is how the pcb looks like in onshape 



i used the transform feature to copy the board and rotate it so that its at a 45 degree angle 

however 55-60 degrees would also work 



however i do want to use the angle to my advantage because then i would be able to hide the wires and the power supply behind the board 



here is the board with the mount and on a 45 degree angle 



now lets open onshape part assembly and put the arduino nano where it should go and other components if i can find their cad file 

oh and here is the arduino nano in onshape after we exported it 



and here is the arduino nano on the main pcb 



i found the a4988 stepper motor driver cad in .step file and im using that to make the mockup , ive linked it to the github repo



now lets import it into the document

and then lets insert it into the assembly

and then lets create the mockup

i created the mockup , i imported the arduino from the public library in onshape and used that because it looks much better than my pcb import 



this wont be the frontend. 
the front end is going to be a screen with the glossy keycaps so lets design that as that will house the raspberry pi aswell  

i totally forgot i have to add the wiring for limit switches aswell 

since i will be programming my own calibration routine at startup so that every joint can find its origin point , i will be using limit switches 

and i will be connecting those limit switches to the microcontroller and to do that i need to add that to the main board which i clearly haven't

just look at this!

i havent added the wiring for the limit swtiches so foolish of me now lets open our pcb schematic and add the limit swtiches 
but before i do that i have to check the amount of limit switches needed and how many pins i have free in the custom arduino nano

to check that i will have to open onshape up and then count the number of limit switch positions ive planned 

i dont need a limit switch in the gripper as im using a servo motor

which doesnt really require me to use a limit switch as ill know the position of the spur gear

since there are 6 degrees of freedom i will be using 6 limit switches

now i dont really want to crowd the main pcb with 6 different switch inputs so i will be distributing it to just 2 pins

here is how that works and my logic behind it. 

what if i asign a specific value to each one of the switches and then connect it to the pwm pin and then
when the microcontroller reads the the valiue using serial input and then knows which switch is which. 

now i dont want to overcrowd the pin by adding 6 switches like that . 

the way ill be adding the switches is that i will be adding a resistor to the wiring of each switch so that when its pressed its going to be of a unique value which the microcontroller will read 

so for this i will be it to 2 pins with 3 switches attached to each one of these and if in the future when i do build this and i need to add another switch , itll be very easy 

now when we open our schematic and see the nano pinout that we have we see that we have d10 and d11 pins free 



here is how ive wired the switches 

i will be now adding the net labels to the nano pinout 

but before i do that let me tell you 

the resistor ive added i didnt want to put on the main pcb but i guess it will be better than adding them in the wires and tucking them behind somewhere, 
so for the switches and the resistors ill be adding the 1x2 pinheader footprints 

now that ive added the footprints 



i will be updating the pcb and adding these

ive changed the resistor footprints to the 2.57mm pinheader ones so that the resistor sits well better 

this is the updated pcb with the limit switch pins added 



the dimentions of the pcb have changed which means i will have to redesign the pcb mount in onshape again 

i have exported the board in .step again aaaaaaaaaaaaaaaaaaaaaaaaaaaaaaaaa im tired now 

i wanted to put the pcb on a angle but it seems that putting it at 90 degrees works better 



and now ill make a stand for this 

here is how that looks like 



now lets make the frontend where the raspberry pi zero with the screen and the 4 keyboard switches will sit 

literally the simplest schematic ive ever made since i wont be puttting anything besides the switches on the pcb 

i will not be ordering the front pcb as its super easy and i can easily make it with a perfboard 

now i only need to create the bom and then submit the project in the hackclub's macondo program

okay so i have to make the readme again and then the bom 

im making the front pcb again because i want this to be perfect

it was hard to find 

but here are the specifications for the display ill be using 



this is my front pcb , however i wont be getting it printed but using a perfboard to make this 

this is just for example 



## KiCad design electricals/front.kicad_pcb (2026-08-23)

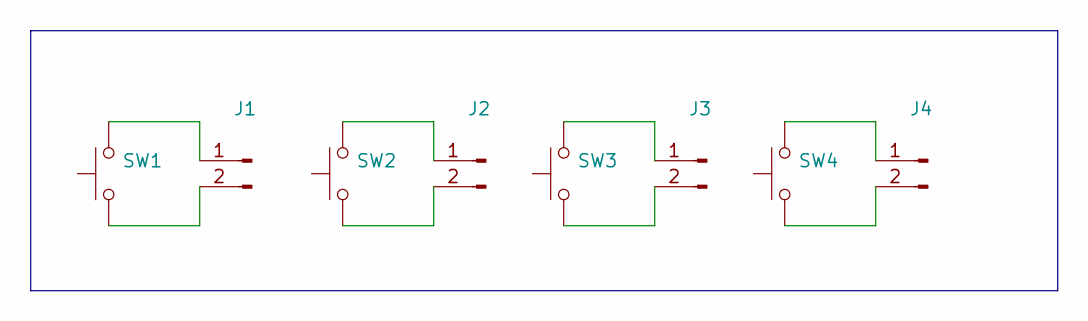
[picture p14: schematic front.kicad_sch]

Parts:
J1, J2, J3, J4: Conn_01x02_Pin; PinHeader_1x02_P1.00mm_Vertical
SW1, SW2, SW3, SW4: SW_Push; SW_Cherry_MX_PCB_1.00u

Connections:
unnamed: J1.1, SW1.2
unnamed: J1.2, SW1.1
unnamed: J2.1, SW2.2
unnamed: J2.2, SW2.1
unnamed: J3.1, SW3.2
unnamed: J3.2, SW3.1
unnamed: J4.1, SW4.2
unnamed: J4.2, SW4.1

Board: 2 copper layers, 8 parts (0 on the bottom side), 8 nets, no tracks yet.

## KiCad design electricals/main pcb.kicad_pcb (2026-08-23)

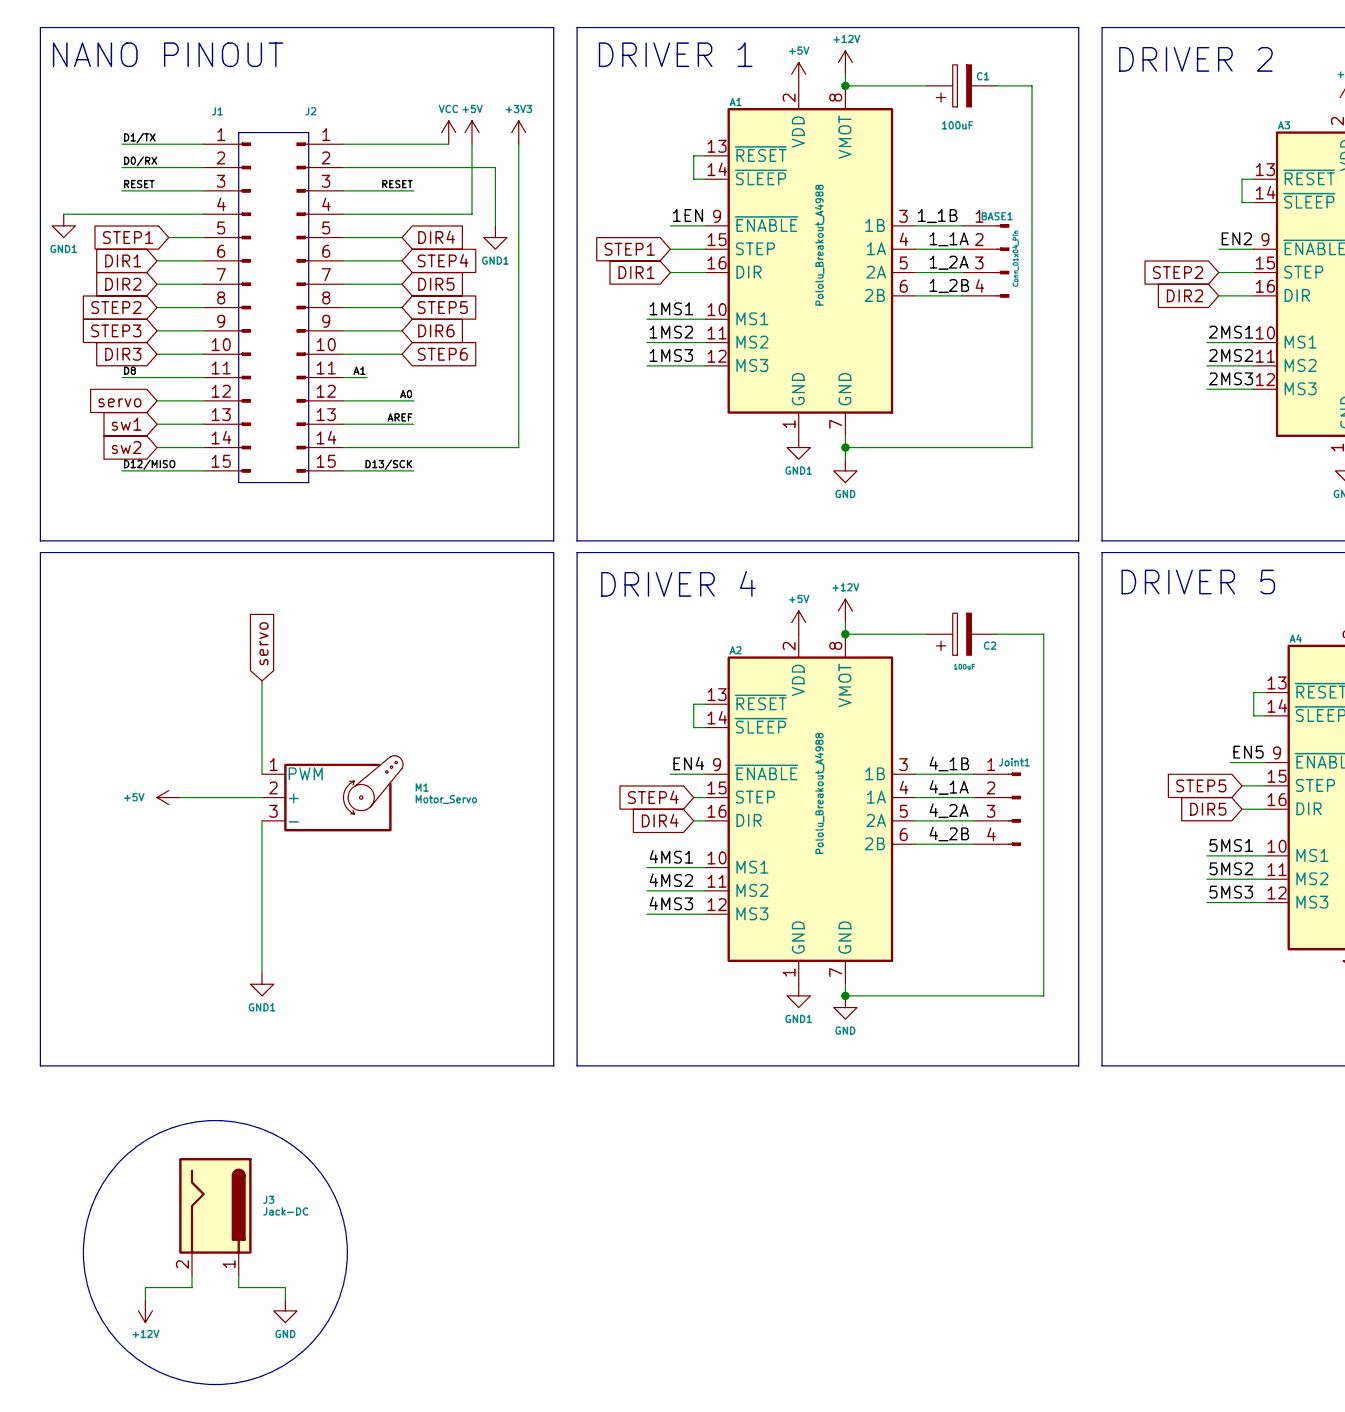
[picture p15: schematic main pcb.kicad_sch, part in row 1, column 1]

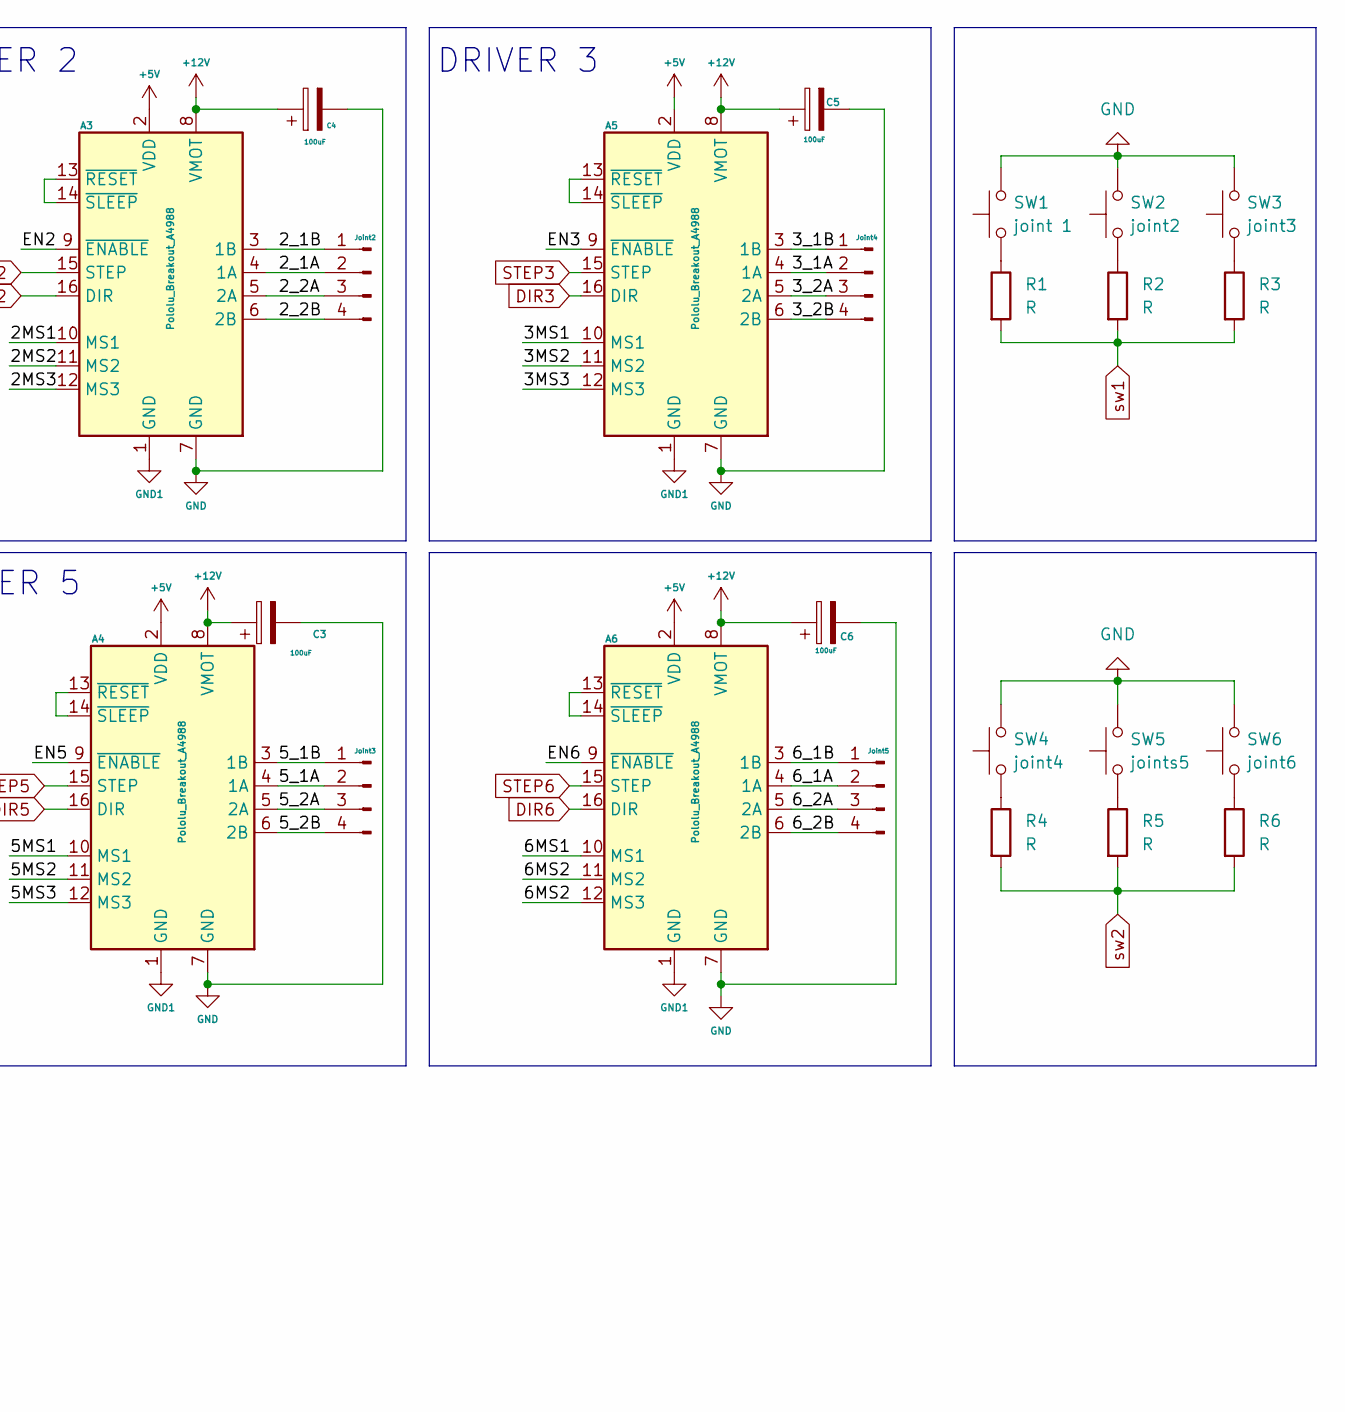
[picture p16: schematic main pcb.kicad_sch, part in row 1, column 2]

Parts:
A1, A2, A3, A4, A5, A6: Pololu_Breakout_A4988; Pololu_Breakout-16_15.2x20.3mm
BASE1: Conn_01x04_Pin; PinHeader_1x04_P2.00mm_Vertical
C1, C2, C3, C4, C5, C6: 100uF; CP_Radial_D8.0mm_P3.50mm
J1, J2: Conn_01x15_Pin; PinHeader_1x15_P2.54mm_Vertical
J3: Jack-DC; PinSocket_1x02_P2.54mm_Vertical
Joint1, Joint2, Joint3, Joint4, Joint5: Conn_01x04_Pin; PinHeader_1x04_P2.00mm_Vertical
M1: Motor_Servo; PinHeader_1x03_P2.54mm_Vertical
R1, R2, R3, R4, R5, R6: R; PinHeader_1x02_P2.54mm_Vertical
SW1: joint 1; PinHeader_1x02_P1.27mm_Vertical
SW2: joint2; PinHeader_1x02_P1.27mm_Vertical
SW3: joint3; PinHeader_1x02_P1.27mm_Vertical
SW4: joint4; PinHeader_1x02_P1.27mm_Vertical
SW5: joints5; PinHeader_1x02_P1.27mm_Vertical
SW6: joint6; PinHeader_1x02_P1.27mm_Vertical

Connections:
+3V3: J2.14
+5V: A1.2 (VDD), A2.2 (VDD), A3.2 (VDD), A4.2 (VDD), A5.2 (VDD), A6.2 (VDD), J2.4, M1.2 (+)
+12V: A1.8 (VMOT), A2.8 (VMOT), A3.8 (VMOT), A4.8 (VMOT), A5.8 (VMOT), A6.8 (VMOT), C1.1, C2.1, C3.1, C4.1, C5.1, C6.1, J3.2
/1EN: A1.9 (~ENABLE)
/1MS1: A1.10 (MS1)
/1MS2: A1.11 (MS2)
/1MS3: A1.12 (MS3)
/1_1A: A1.4 (1A), BASE1.2
/1_1B: A1.3 (1B), BASE1.1
/1_2A: A1.5 (2A), BASE1.3
/1_2B: A1.6 (2B), BASE1.4
/2MS1: A3.10 (MS1)
/2MS2: A3.11 (MS2)
/2MS3: A3.12 (MS3)
/2_1A: A3.4 (1A), Joint2.2
/2_1B: A3.3 (1B), Joint2.1
/2_2A: A3.5 (2A), Joint2.3
/2_2B: A3.6 (2B), Joint2.4
/3MS1: A5.10 (MS1)
/3MS2: A5.11 (MS2)
/3MS3: A5.12 (MS3)
/3_1A: A5.4 (1A), Joint4.2
/3_1B: A5.3 (1B), Joint4.1
/3_2A: A5.5 (2A), Joint4.3
/3_2B: A5.6 (2B), Joint4.4
/4MS1: A2.10 (MS1)
/4MS2: A2.11 (MS2)
/4MS3: A2.12 (MS3)
/4_1A: A2.4 (1A), Joint1.2
/4_1B: A2.3 (1B), Joint1.1
/4_2A: A2.5 (2A), Joint1.3
/4_2B: A2.6 (2B), Joint1.4
/5MS1: A4.10 (MS1)
/5MS2: A4.11 (MS2)
/5MS3: A4.12 (MS3)
/5_1A: A4.4 (1A), Joint3.2
/5_1B: A4.3 (1B), Joint3.1
/5_2A: A4.5 (2A), Joint3.3
/5_2B: A4.6 (2B), Joint3.4
/6MS1: A6.10 (MS1)
/6MS2: A6.11 (MS2), A6.12 (MS3)
/6_1A: A6.4 (1A), Joint5.2
/6_1B: A6.3 (1B), Joint5.1
/6_2A: A6.5 (2A), Joint5.3
/6_2B: A6.6 (2B), Joint5.4
/A0: J2.12
/A1: J2.11
/AREF: J2.13
/D0/RX: J1.2
/D1/TX: J1.1
/D8: J1.11
/D12/MISO: J1.15
/D13/SCK: J2.15
/EN2: A3.9 (~ENABLE)
/EN3: A5.9 (~ENABLE)
/EN4: A2.9 (~ENABLE)
/EN5: A4.9 (~ENABLE)
/EN6: A6.9 (~ENABLE)
/RESET: J1.3, J2.3
DIR1: A1.16 (DIR), J1.6
DIR2: A3.16 (DIR), J1.7
DIR3: A5.16 (DIR), J1.10
DIR4: A2.16 (DIR), J2.5
DIR5: A4.16 (DIR), J2.7
DIR6: A6.16 (DIR), J2.9
GND: A1.7 (GND), A2.7 (GND), A3.7 (GND), A4.7 (GND), A5.7 (GND), A6.7 (GND), C1.2, C2.2, C3.2, C4.2, C5.2, C6.2, J3.1, SW1.2, SW2.2, SW3.2, SW4.2, SW5.2, SW6.2
GND1: A1.1 (GND), A2.1 (GND), A3.1 (GND), A4.1 (GND), A5.1 (GND), A6.1 (GND), J1.4, J2.2, M1.3 (-)
unnamed: A1.13 (~RESET), A1.14 (~SLEEP)
unnamed: A2.13 (~RESET), A2.14 (~SLEEP)
unnamed: A3.13 (~RESET), A3.14 (~SLEEP)
unnamed: A4.13 (~RESET), A4.14 (~SLEEP)
unnamed: A5.13 (~RESET), A5.14 (~SLEEP)
unnamed: A6.13 (~RESET), A6.14 (~SLEEP)
unnamed: R1.1, SW1.1
unnamed: R2.1, SW2.1
unnamed: R3.1, SW3.1
unnamed: R4.1, SW4.1
unnamed: R5.1, SW5.1
unnamed: R6.1, SW6.1
STEP1: A1.15 (STEP), J1.5
STEP2: A3.15 (STEP), J1.8
STEP3: A5.15 (STEP), J1.9
STEP4: A2.15 (STEP), J2.6
STEP5: A4.15 (STEP), J2.8
STEP6: A6.15 (STEP), J2.10
VCC: J2.1
servo: J1.12, M1.1 (PWM)
sw1: J1.13, R1.2, R2.2, R3.2
sw2: J1.14, R4.2, R5.2, R6.2

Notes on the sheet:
DRIVER 5
DRIVER 2
DRIVER 4
DRIVER 1
NANO PINOUT
DRIVER 3

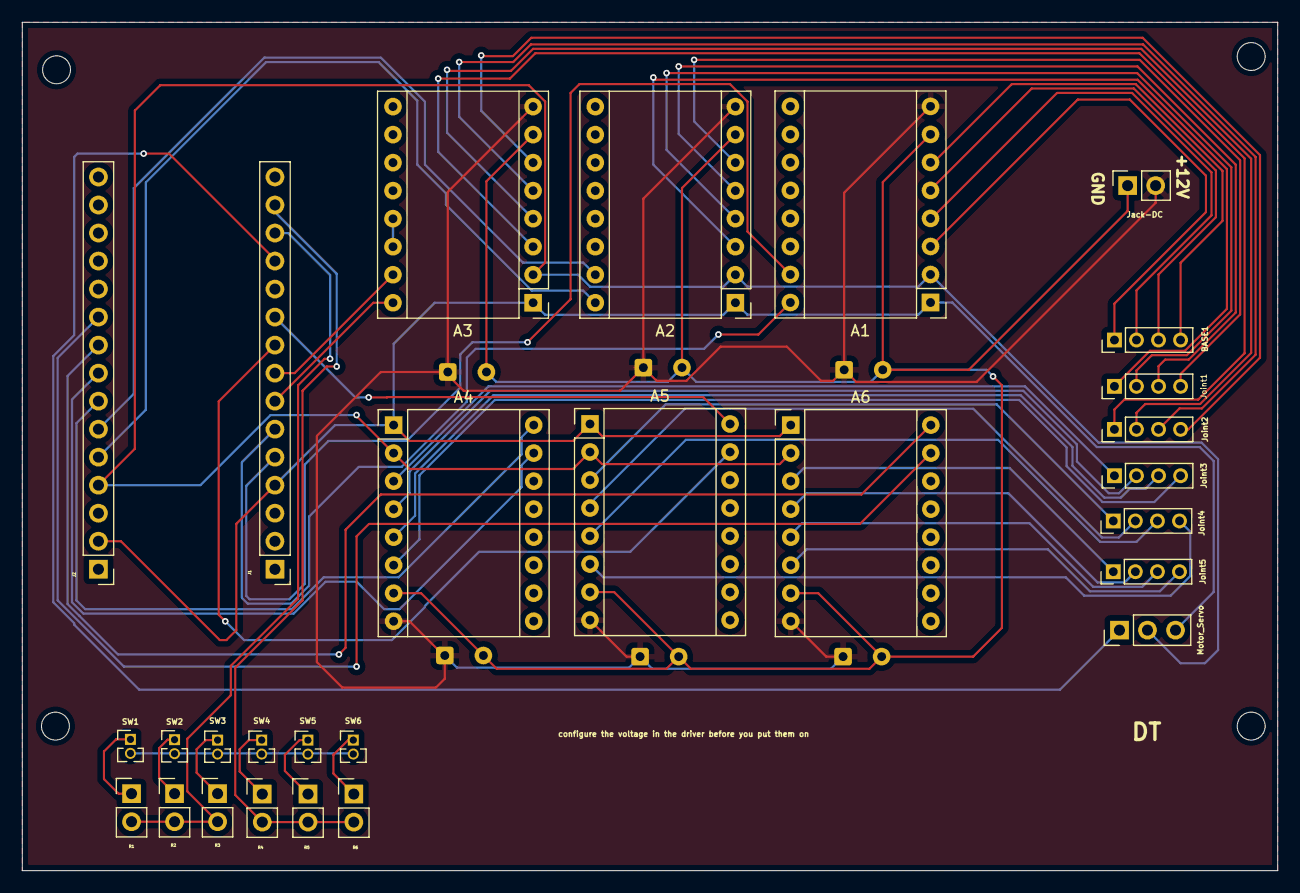
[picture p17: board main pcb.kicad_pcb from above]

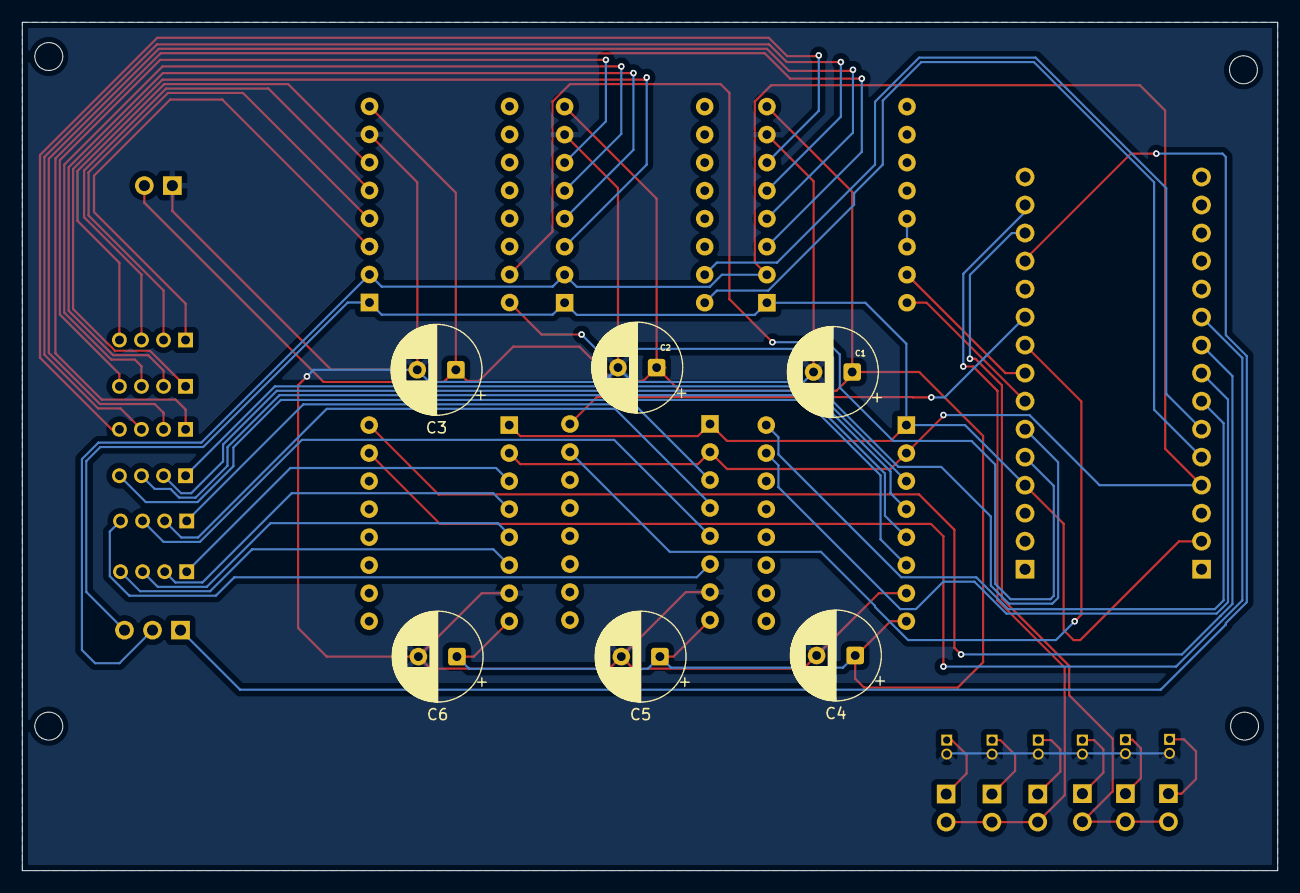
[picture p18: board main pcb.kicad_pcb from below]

Board: 2 copper layers, 113.8 x 76.9 mm, 34 parts (6 on the bottom side), 57 nets.

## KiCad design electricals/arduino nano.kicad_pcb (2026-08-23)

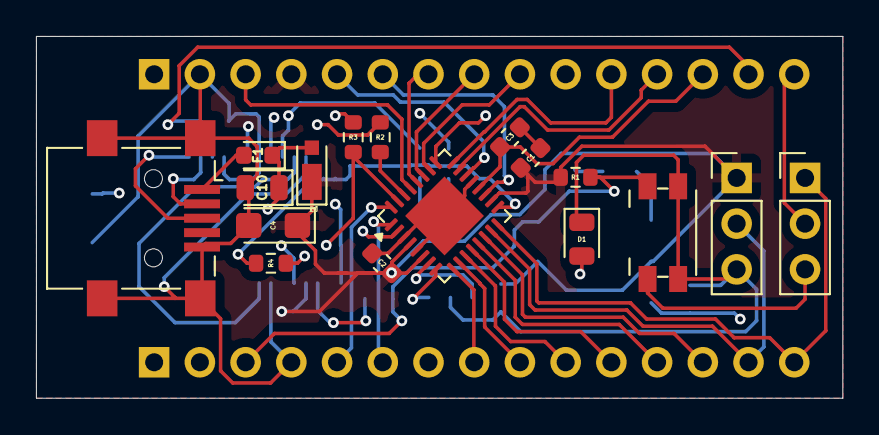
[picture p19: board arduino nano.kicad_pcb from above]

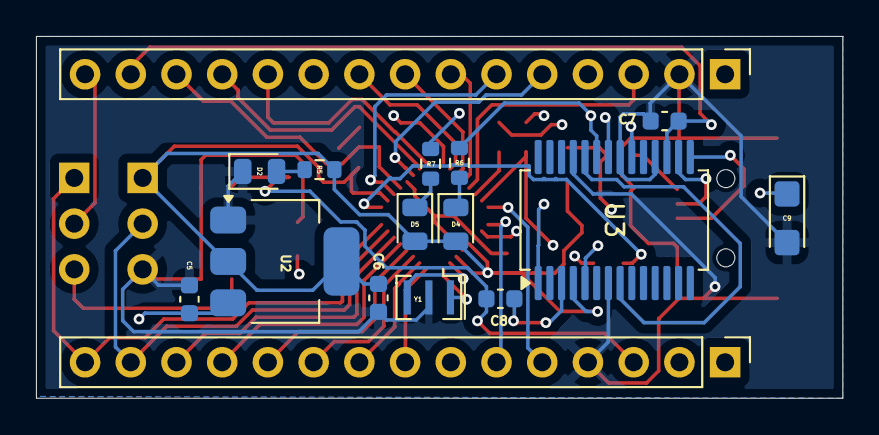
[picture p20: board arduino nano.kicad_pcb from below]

Board: 4 copper layers, 44.8 x 20.1 mm, 33 parts (16 on the bottom side), 43 nets.

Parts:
C1, C2, C5, C6: 1u; C_0603_1608Metric
C3, C7, C8: 100n; C_0603_1608Metric
C4, C9: 4u7_ 16V; CP_EIA-3216-10_Kemet-I
C10: 100n; LED_0805_2012Metric
D1: YELLOW; LED_0805_2012Metric
D2, D5: GREEN; LED_0805_2012Metric
D3: DIODE; D_MicroSMP_AK
D4: RED; LED_0805_2012Metric
F1: 0603; D_0603_1608Metric
J1: USB_B_Mini; USB_Mini-B_Lumberg_2486_01_Horizontal
J2, J4: Conn_01x15_Pin; PinHeader_1x15_P2.54mm_Vertical
J3: ICSP; PinHeader_1x03_P2.54mm_Vertical
J5: Conn_01x03_Pin; PinHeader_1x03_P2.54mm_Vertical
R1, R2, R3, R4, R5, R6, R7: 1K; R_0603_1608Metric
SW1: SW_Push; Panasonic_EVQPUK_EVQPUB
U1: ATmega328P-M; QFN-32-1EP_5x5mm_P0.5mm_EP3.1x3.1mm
U2: LM1117MP-5.0; SOT-223-3_TabPin2
U3: FT232RL; SSOP-28_5.3x10.2mm_P0.65mm
Y1: 16MHz; Resonator_SMD_Murata_CSTxExxV-3Pin_3.0x1.1mm

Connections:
+3V3: C7.1, J2.14, U3.17 (3V3OUT)
+5V: C1.1, C2.1, C4.1, C6.1, D3.1 (K), D4.2 (A), D5.2 (A), J2.4, J3.1, R1.1, R5.2, U1.4 (VCC), U1.6 (VCC), U1.18 (AVCC), U2.2 (VO), U3.4 (VCCIO), U3.20 (VCC)
/A0: J2.12, U1.23 (PC0)
/A1: J2.11, U1.24 (PC1)
/A2: J2.10, U1.25 (PC2)
/A3: J2.9, U1.26 (PC3)
/A4: J2.8, U1.27 (PC4)
/A5: J2.7, U1.28 (PC5)
/A6: J2.6, U1.19 (ADC6)
/A7: J2.5, U1.22 (ADC7)
/AREF: C3.1, J2.13, U1.20 (AREF)
/D1/TX: J4.1, R3.1, U1.31 (PD1)
/D2: J4.5, U1.32 (PD2)
/D3: J4.6, U1.1 (PD3)
/D4: J4.7, U1.2 (PD4)
/D5: J4.8, U1.9 (PD5)
/D6: J4.9, U1.10 (PD6)
/D7: J4.10, U1.11 (PD7)
/D8: J4.11, U1.12 (PB0)
/D9: J4.12, U1.13 (PB1)
/D10: J4.13, U1.14 (PB2)
/D11/MOSI: J3.2, J4.14, U1.15 (PB3)
/D12/MISO: J4.15, J5.1, U1.16 (PB4)
/D13/SCK: J2.15, J5.2, R4.2, U1.17 (PB5)
/DO/RX: R2.1, U1.30 (PD0)
/D_N: J1.2 (D-), U3.16 (USBD-)
/D_P: J1.3 (D+), U3.15 (USBD+)
/RESET: C8.1, J2.3, J4.3, J5.3, R1.2, SW1.1, U1.29 (~RESET/PC6)
/RX: R2.2, U3.5 (RXD)
/TX: R3.2, U3.1 (TXD)
/XTAL1: U1.7 (XTAL1/PB6), Y1.3
/XTAL2: U1.8 (XTAL2/PB7), Y1.1
GND: C1.2, C2.2, C3.2, C4.2, C5.2, C6.2, C7.2, C9.2, C10.2, D1.1 (K), D2.1 (K), J1.5 (GND), J1.6 (Shield), J2.2, J3.3, J4.4, SW1.2, U1.3 (GND), U1.5 (GND), U1.21 (GND), U1.33 (GND), U2.1 (GND), U3.7 (GND), U3.18 (GND), U3.21 (GND), U3.25 (AGND), Y1.2
unnamed: D1.2 (A), R4.1
unnamed: D2.2 (A), R5.1
unnamed: D4.1 (K), R6.1
unnamed: D5.1 (K), R7.1
unnamed: F1.2, J1.1 (VBUS)
unnamed: R6.2, U3.23 (CBUS0)
unnamed: R7.2, U3.22 (CBUS1)
unnamed: C8.2, U3.3 (RTS)
VBUS: C9.1, C10.1, D3.2 (A), F1.1
VCC: C5.1, J2.1, U2.3 (VI)

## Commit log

2026-08-16 Update journal with details on sun gear connection
    Clarify the connection of the sun gear to the stepper motor.
2026-08-18 Document robotic arm design process and mechanism
    Added details about the robotic arm base design and its mechanism.
2026-08-18 Update journal with reflection and resource link
    Added personal reflection and resource link for learning about gears.
2026-08-19 Insert image in journal entry
    Added an image to the journal entry.
2026-08-19 Remove final schematic section from journal.md
2026-08-19 Insert image of main board PCB
    Added an image of the main board PCB to the journal.
2026-08-22 Document frontend setup for Raspberry Pi project
    Added a note about creating the frontend for the Raspberry Pi setup.
2026-08-23 Rename robotic_arm_additional_bom.csv to robotic arm bom.csv
    [robotic arm bom.csv]
